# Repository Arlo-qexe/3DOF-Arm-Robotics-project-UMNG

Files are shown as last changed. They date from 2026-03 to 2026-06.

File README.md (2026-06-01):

# Brazo Robótico 3DOF — Proyecto UMNG

Diseño, construcción y control de un brazo robótico de 3 grados de libertad (3-DOF) capaz de ejecutar tareas de manipulación autónoma. El proyecto abarca desde el diseño CAD y simulación hasta la implementación física completa: electrónica, firmware en ESP32, interfaz de control y planificación de trayectorias.

> **Aplicación demo:** clasificación y transporte autónomo de pelotas de ping pong entre posiciones predefinidas.

---

## Robot físico

| Vista lateral | Vista frontal (laboratorio) |
|---|---|
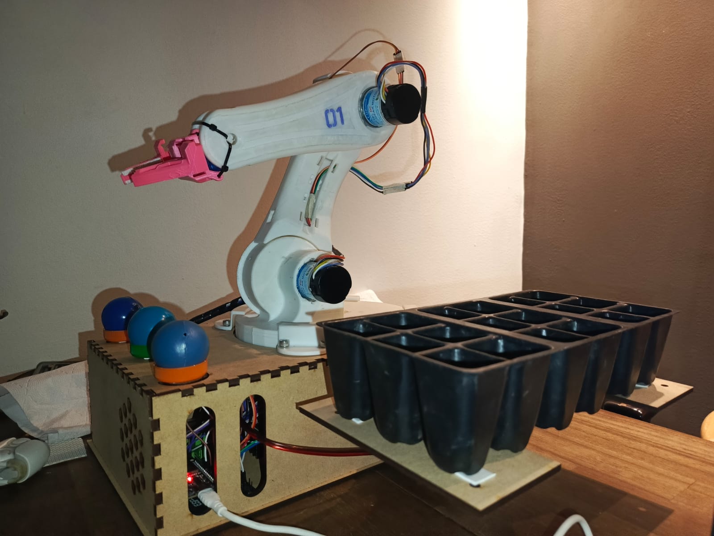
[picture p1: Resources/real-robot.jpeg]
Robot real
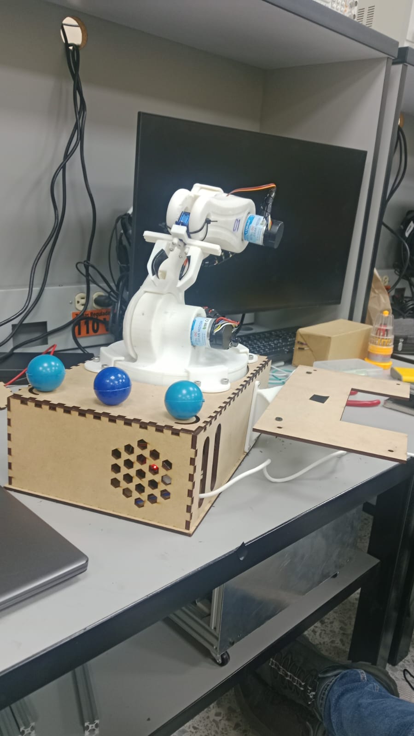
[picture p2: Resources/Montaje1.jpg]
Robot en laboratorio
|  |  |

---

## 🎯 Objetivos

### Objetivo general
Diseñar, construir y controlar un brazo robótico de 3 DOF capaz de posicionar su efector final mediante cinemática directa e inversa, y ejecutar tareas de manipulación autónoma con trayectorias planificadas.

### Objetivos específicos
- Diseñar la estructura mecánica completa (CAD + impresión 3D + corte láser)
- Diseñar e implementar el circuito electrónico de control (PCB personalizada)
- Modelar matemáticamente el sistema (cinemática directa e inversa, Jacobiano)
- Implementar firmware en ESP32 para control de 3 motores DC con encoders
- Desarrollar una interfaz gráfica de control y monitoreo en Python
- Implementar un simulador de planificación de trayectorias
- Integrar simulación en ROS2/Gazebo con modelo URDF
- Ejecutar la tarea de clasificación de pelotas de ping pong

---

## 📂 Estructura del repositorio

```
├── Act/                          → Actas de reuniones del proyecto
├── Documentos/                   → Análisis de contexto y documentación
├── Hardware/
│   ├── CAD/                      → Diseños CAD (SolidWorks, DXF)
│   ├── PCB/                      → PCB personalizada (ESP32 + BTS7960 + 3 motores DC)
│   ├── Gripper/                  → Modelo STL del gripper
│   ├── STLs/ y STLS/             → Piezas impresas en 3D
│   └── Engranaje de Eslabon*.png → Renders de engranajes
├── Resources/
│   ├── VIDEOS/                   → Videos de pruebas y resultado final
│   ├── Trayectorias/             → CSVs de trayectorias (articular y cartesiana)
│   ├── Datos caracterizacion Motores/ → Datos encoder de los 3 motores
│   └── *.png / *.jpg             → Imágenes del proyecto
├── Software/
│   ├── brazo_integrado (4).py    → Interfaz principal de control + planificador
│   ├── abdul3dof_gui.py          → GUI de control de posición
│   ├── Gazebo/                   → Simulación en Gazebo (URDF, workspace ROS2)
│   ├── URDF/                     → Modelo URDF del brazo
│   ├── brazo_robot/              → Paquete ROS2 del robot
│   └── ws_manip/                 → Workspace de manipulación ROS2
├── README.md
└── LICENSE
```

---

## 🔧 Hardware

### Diseño mecánico (SolidWorks)

El brazo fue diseñado completamente en SolidWorks e impreso en 3D. Incluye tres eslabones, base giratoria, gripper y bandeja dispensadora de pelotas.

| Ensamblaje completo | Ensamblaje v1 |
|---|---|
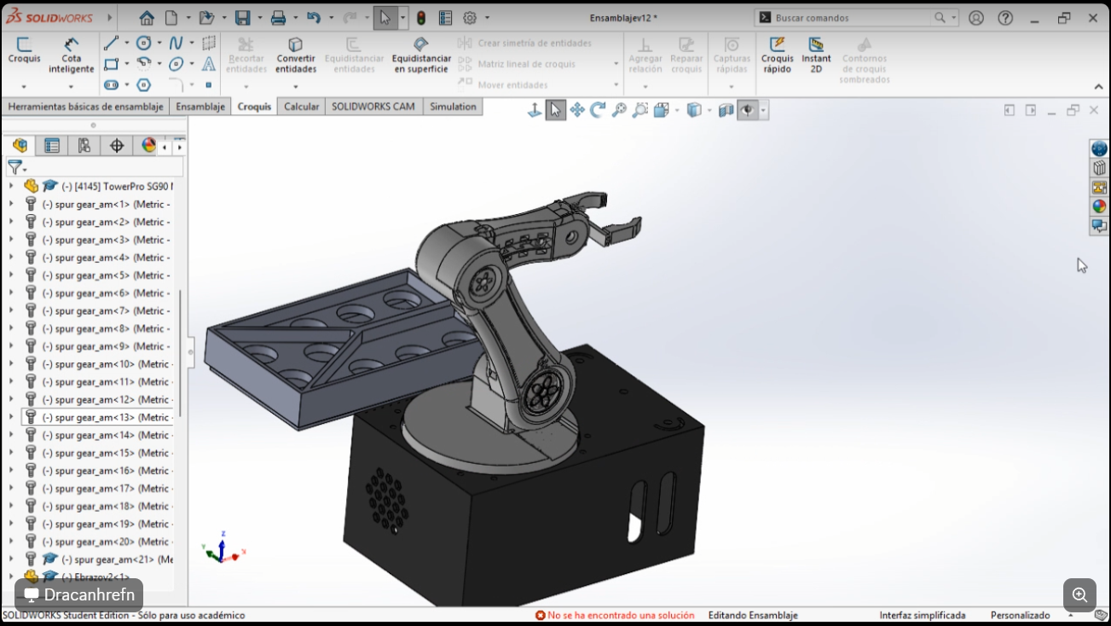
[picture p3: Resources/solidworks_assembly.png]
SolidWorks ensamblaje
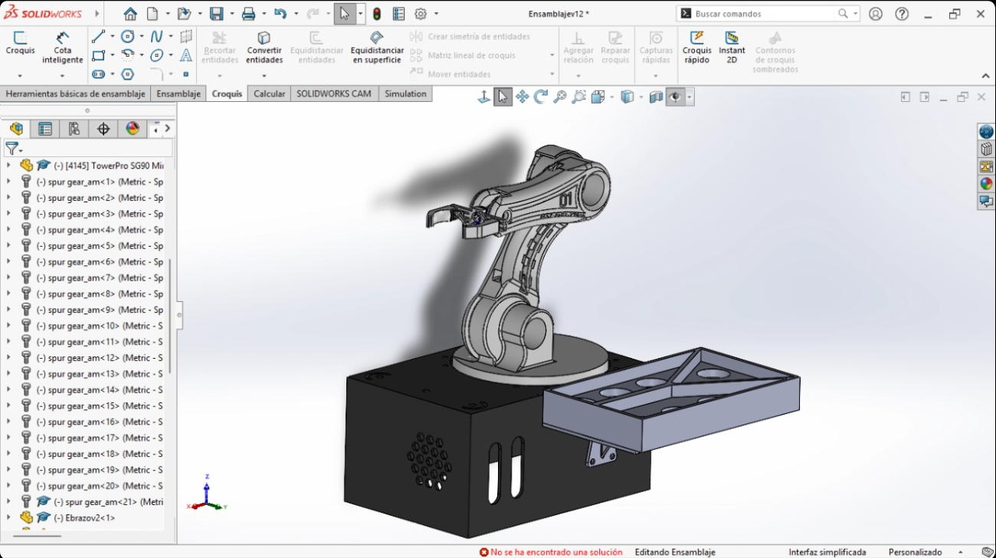
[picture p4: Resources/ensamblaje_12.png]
Ensamblaje anterior
|  |  |

| Dimensiones dispensador | Bandeja ping pong (impresa) |
|---|---|
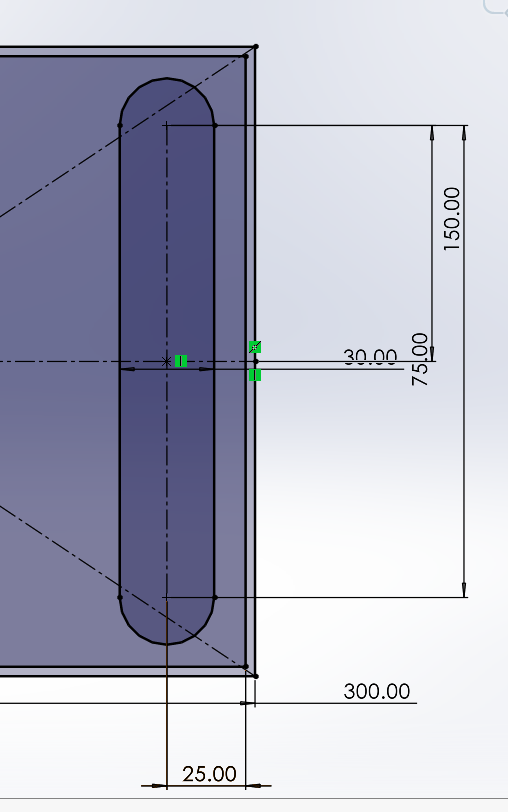
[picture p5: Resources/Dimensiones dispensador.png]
Dimensiones dispensador
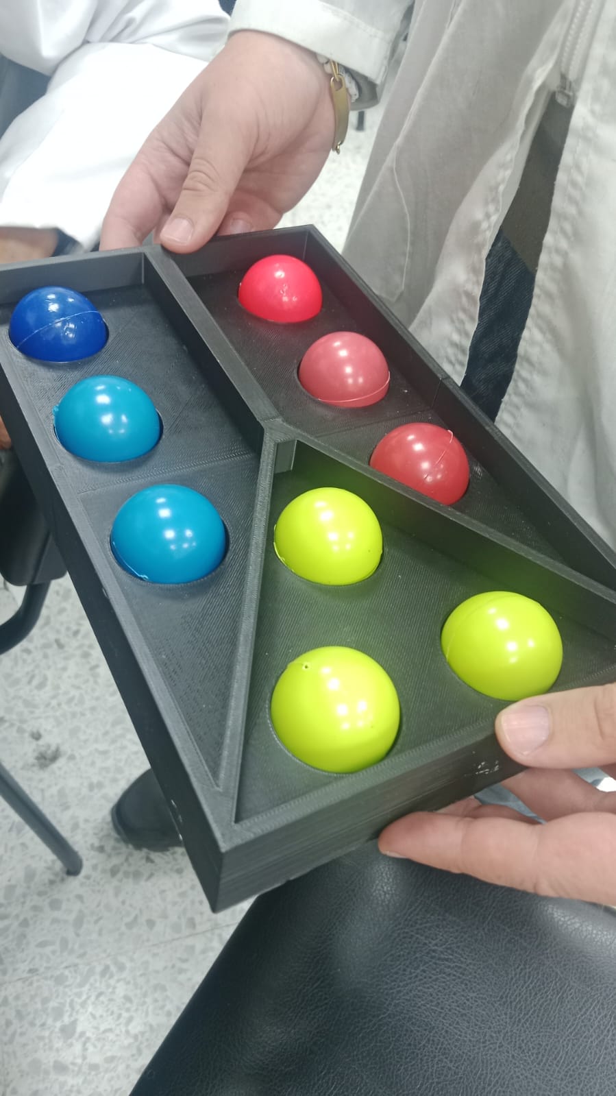
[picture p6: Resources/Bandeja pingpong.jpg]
Bandeja ping pong
|  |  |

### Electrónica — PCB personalizada

Se diseñó e implementó una PCB a medida con:
- **ESP32** como microcontrolador principal
- **BTS7960** (×3) para control de motores DC con PWM
- Conectores de encoder para los 3 motores
- Fabricada en Bogotá (2026-04-10)

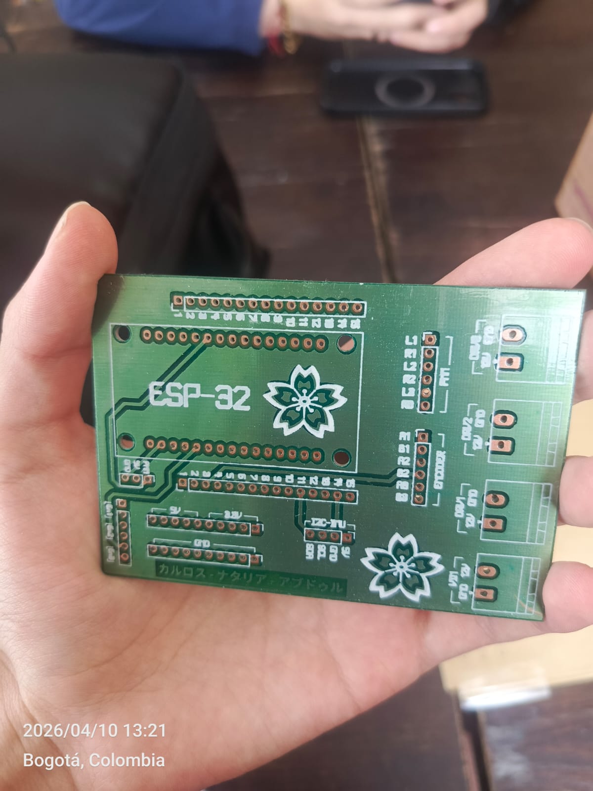
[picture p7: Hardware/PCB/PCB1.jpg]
PCB ESP32 + BTS7960


El esquemático completo está disponible en: [`Resources/Esquemático – ESP32 + BTS7960 + 3 Motores DC.pdf`](Resources/Esquemático%20–%20ESP32%20+%20BTS7960%20+%203%20Motores%20DC.pdf)

---

## 💻 Software

### Interfaz de control de posición

Interfaz gráfica en Python (`abdul3dof_gui.py`) con conexión serial al ESP32:

- Control independiente de 3 motores (M1 Base, M2 Hombro, M3 Codo)
- Visualización 3D en tiempo real de cinemática directa
- Gráfica de posición articular en tiempo real
- Cálculo y ejecución de cinemática inversa
- Reset de posición con un clic

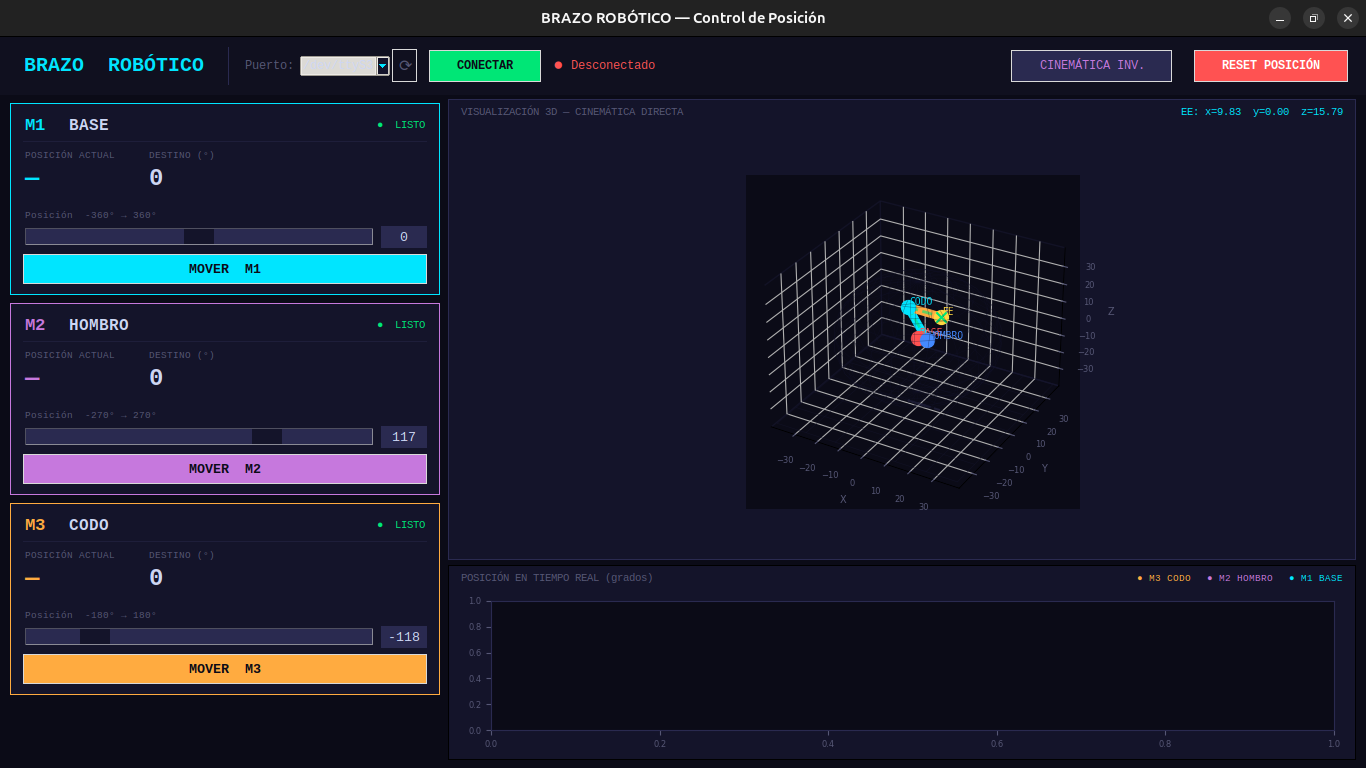
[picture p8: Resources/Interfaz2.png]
Interfaz de control de posición


### Simulador de planificación de trayectorias

El simulador integrado (`brazo_integrado (4).py`) permite planificar y animar trayectorias completas:

- Editor de waypoints (XYZ o articular)
- 3 modos de interpolación: **articular (curva)**, **cartesiana (recta)**, **control cinemático (Jacobiano)**
- Visualización 3D animada de la trayectoria del efector final
- Gráficas: posición articular, velocidad, aceleración y posición XYZ del EE
- Importación de trayectorias desde CSV
- Gripper integrado en la simulación
- Resumen automático: waypoints, tramos, tiempo total

| Planificador de trayectorias (ping pong articular) | Ángulos enviados / control real |
|---|---|
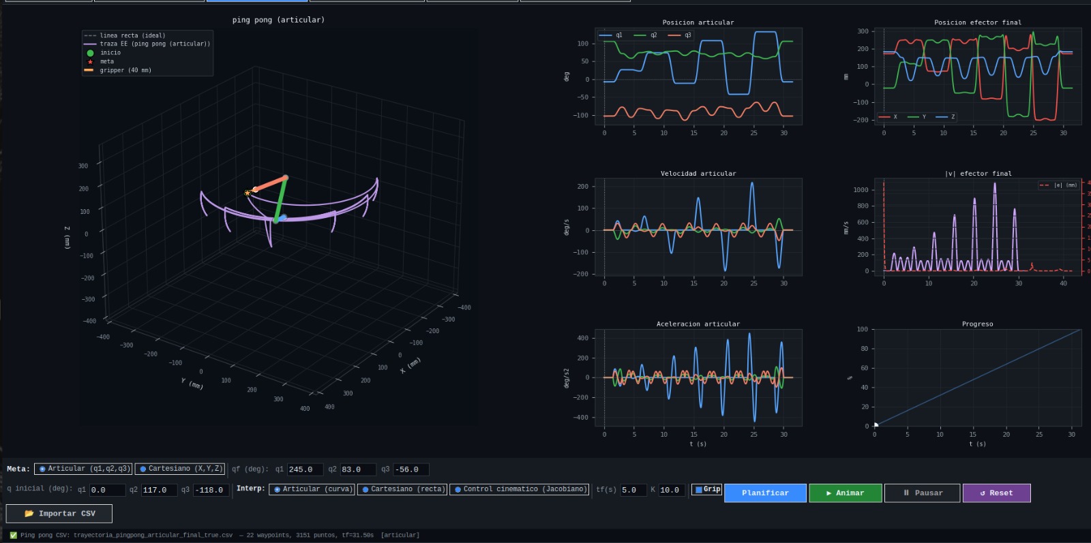
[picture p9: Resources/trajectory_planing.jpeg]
Planificador
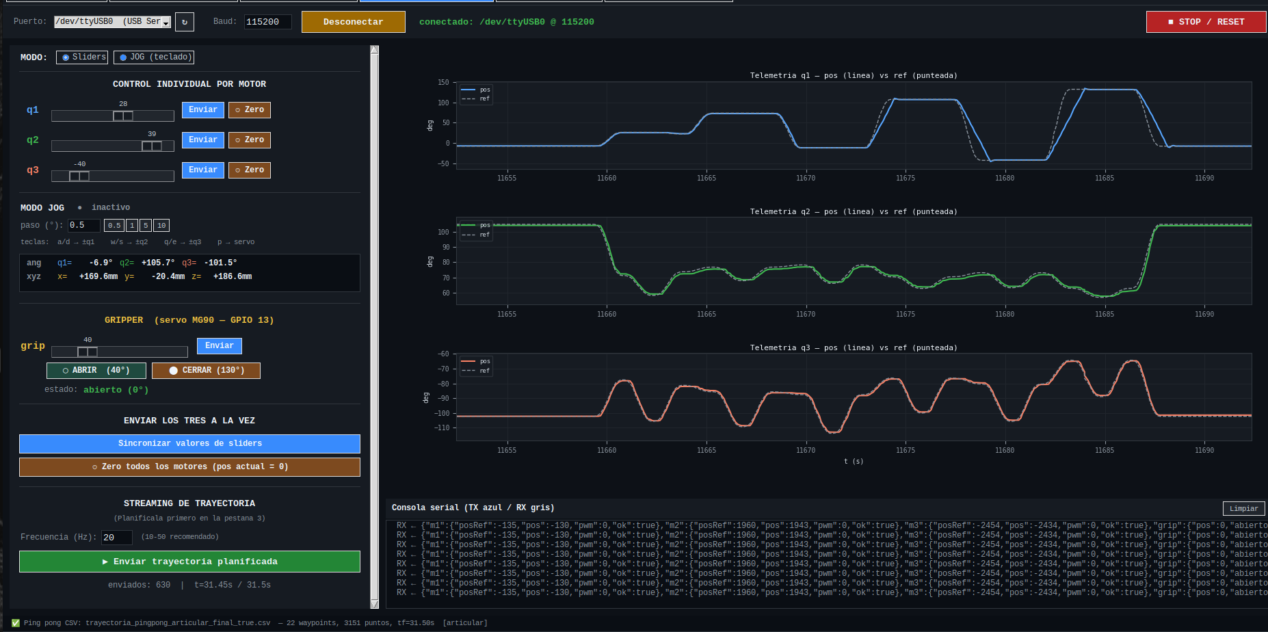
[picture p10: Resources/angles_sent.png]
Ángulos enviados
|  |  |

**Trayectoria ping pong:** 22 waypoints, 21 tramos, tiempo total ≈ 31.5 s, gripper 40 mm de apertura.

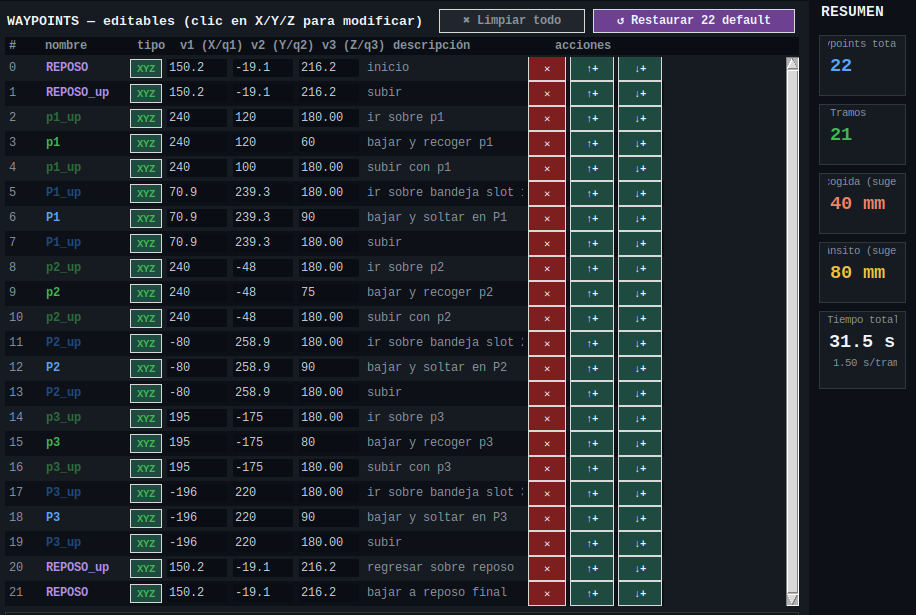
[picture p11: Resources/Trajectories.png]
Waypoints ping pong


### Simulación ROS2 / Gazebo

Simulación completa con modelo URDF en Gazebo y visualización en RViz:

| RViz — modelo 3D | Gazebo + interfaz Python |
|---|---|
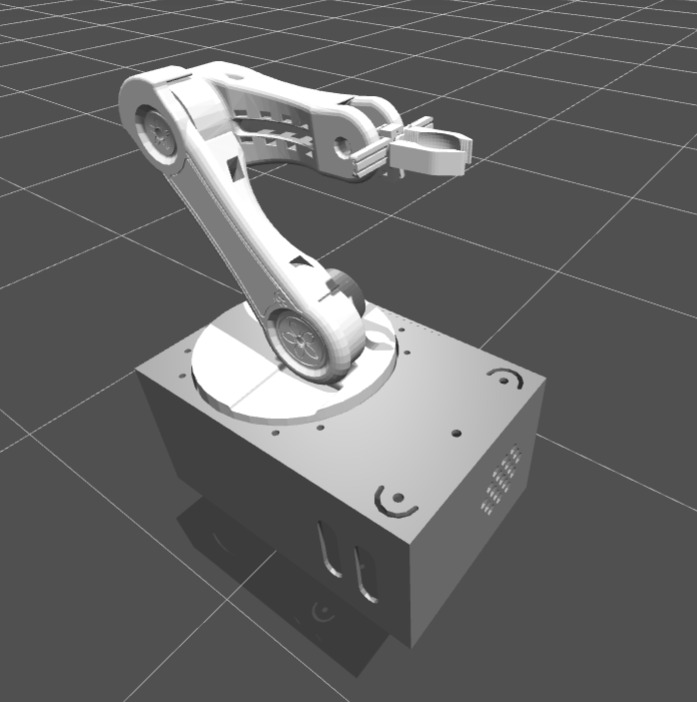
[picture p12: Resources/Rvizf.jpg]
RViz
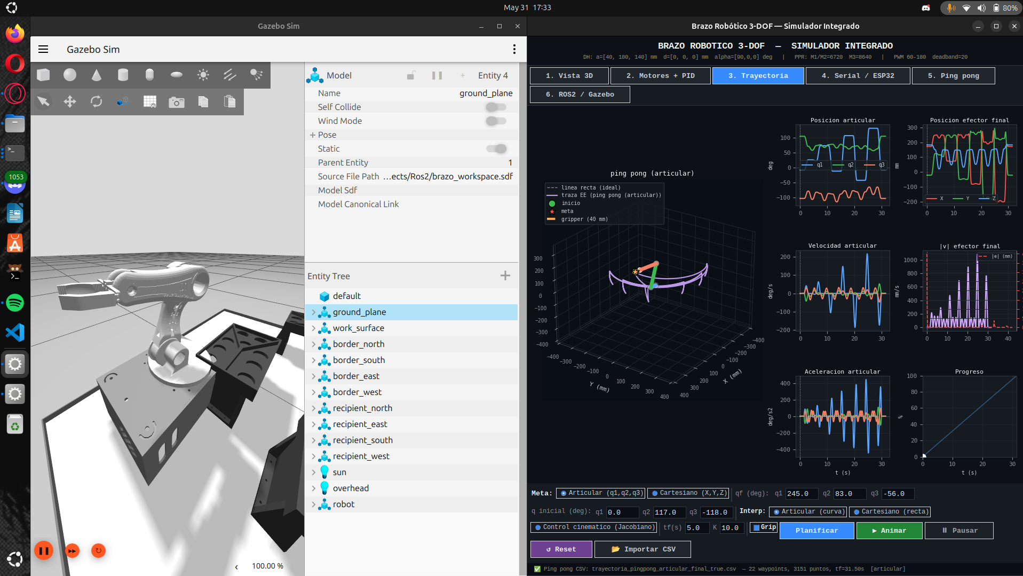
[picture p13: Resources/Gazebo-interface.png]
Gazebo + interfaz
|  |  |

### Cinemática inversa interactiva

Archivo HTML autocontenido (`Resources/cinematica_inversa_interactiva.html`) para explorar visualmente la cinemática inversa del brazo en el navegador, sin instalación adicional.

---

## 🏓 Aplicación: clasificación de pelotas de ping pong

El robot ejecuta una secuencia autónoma de pick & place: recoge pelotas del dispensador y las deposita en posiciones predefinidas de una bandeja receptora.

- **Dispensador:** bandeja 3D-impresa con ranuras para pelotas de colores
- **Gripper:** pinza impresa en 3D (apertura 40 mm)
- **Trayectoria:** planificada con el simulador y cargada via CSV al firmware
- **Ejecución:** ~31.5 s por ciclo completo (3 pelotas)

**Video — prueba final:**
<video src="https://raw.githubusercontent.com/Arlo-qexe/3DOF-Arm-Robotics-project-UMNG/main/Resources/VIDEOS/video_final.mp4" controls width="720"></video>
Más videos de prueba en [`Resources/VIDEOS/`](Resources/VIDEOS/)

---

## 📊 Caracterización de motores

Se midieron y registraron curvas de velocidad y posición (encoder) para los 3 motores bajo distintas condiciones:

```
Resources/Datos caracterizacion Motores/
├── M1_Encoder_data_210.csv
├── M2_Encoder_data_rads_210.csv
├── M3_Encoder_data_rads_270.csv
└── ...
```

---

## 👩‍💻 Autores

Proyecto desarrollado por estudiantes de Ingeniería — **Universidad Militar Nueva Granada (UMNG)**:

- **Carlos Andrés Quintero Forero**
- **Salim Abdul Fayad Diaz**
- **Natalia Almanza**

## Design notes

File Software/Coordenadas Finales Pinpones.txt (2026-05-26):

Coordenadas Finales Pinpones:
	z = -50m (+20mm con altura pingpong + 80mm movimiento previo)
	y = +162.99mm
	x1= -34.87mm
	x2= +25.13mm
	x3= +85.13mm
Coordenadas Recogida Pinpones:

	z = -50mm (+20mm con altura pingpong)
	x = 172mm
	y = 75mm

Coordenadas Descanso:

	z = 197.01mm
	x = 125.23mm
	y = 19.87mm

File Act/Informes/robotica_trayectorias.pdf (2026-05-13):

# Planificación Trapezoidal de Trayectorias Articulares

### Natalia Almanza, Abdul Fayad, Carlos Quintero

### 27 de marzo de 2026

## 1. Fundamento Teórico

### 1.1. Perfil Trapezoidal

El perfil trapezoidal de velocidad consta de tres fases:

Aceleración constante

Velocidad constante

Desaceleración constante

El tiempo de aceleración se define como:

ta =

Vmax
a

(1)

La distancia recorrida durante la aceleración es:

da =

1
2

at²
a

(2)

Dependiendo del desplazamiento total D, el perfil puede ser:

Triangular: no se alcanza la velocidad máxima.

Trapezoidal: existe fase de velocidad constante.

### 1.2. Sincronización Temporal

Cada articulación posee un tiempo natural distinto. Para sincronizar el movimiento se utiliza un factor de escala temporal:

ratio =

ttotal
tf

(3)

Recalculando:

t

′
a = ratio · ta | (4)
t

′
c = ratio · tc | (5)

La nueva velocidad pico queda:

Vp =

|D|
t

′
a + t

′
c

(6)

y la aceleración:

aj =

Vp
t

′
a

(7)

## 2. Metodología

El algoritmo desarrollado sigue los siguientes pasos:

1. Definición del tiempo total de movimiento.
2. Establecimiento de posiciones iniciales y finales.
3. Cálculo del perfil natural de cada junta.
4. Escalamiento temporal.
5. Generación de posición, velocidad y aceleración.
6. Visualización gráfica.

## 3. Código Implementado

clc; clear ; close all;

t_total = 5;
dt = 0.001;
t = 0: dt : t_total ;
n = length ( t ) ;

q0 = [0 117 -118];
qf = [245 83 -56];

Vmax = [20 15 10];
a = [10 10 10];

q = zeros (3 , n ) ;
qd = zeros (3 , n ) ;
qdd = zeros (3 , n ) ;

tf_vec = zeros (1 ,3) ;
Vp_vec = zeros (1 ,3) ;
ta_vec = zeros (1 ,3) ;
tc_vec = zeros (1 ,3) ;

for j = 1:3

25 D = qf ( j ) - q0 ( j ) ;

26
27 | ta = Vmax ( j ) / a ( j ) ;
28 | da = 0.5* a ( j ) * ta ^2;

29
30 | if (2* da > abs( D ) )
31 | ta = sqrt (abs( D ) / a ( j ) ) ;
32 | tc = 0;
33 | tf = 2* ta ;
34 | Vp = a ( j ) * ta ;
35 | else
36 | tc = (abs( D ) -2* da ) / Vmax ( j ) ;
37 | tf = 2* ta + tc ;
38 | Vp = Vmax ( j ) ;
39 | end

40
41 | tf_vec ( j ) = tf ;
42 | Vp_vec ( j ) = Vp ;
43 | ta_vec ( j ) = ta ;
44 | tc_vec ( j ) = tc ;
45 | end

## 4. Resultados

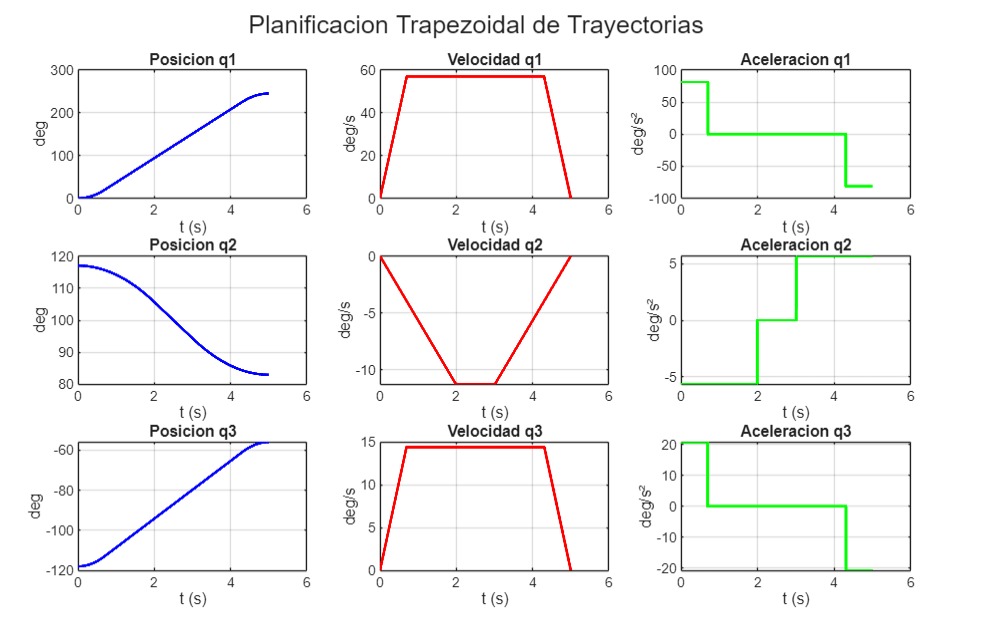
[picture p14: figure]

Figura 1: Gráficas resultados velocidad trapezoidal

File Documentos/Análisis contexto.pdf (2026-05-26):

INFORME DE PRÁCTICA DE LABORATORIO | Versión 1.0
PROGRAMA DE INGENIERÍA MECATRÓNICA
Periodo 2024-2

## Análisis de Contexto: Sistema Robótico de Ensamble Pick-and-Place de 3 GDL para Líneas de Empaque Industrial

Carlos Andrés Quintero Forero, Natalia Almanza Velasco, Abdul Ingeniería en Mecatrónica — Universidad Militar Nueva Granada

Profesora: Alexandra Elizabeth Velasco

Resumen—Este documento presenta el análisis de contexto de dos sistemas robóticos manipuladores antropomórficos de 3 grados de libertad (GDL) diseñados para tareas de pick-and-place en líneas de empaque industrial. El primer sistema atiende el empaque de chocolates individuales en una
caja, | bajo | restricciones | de | higiene
alimentaria. El segundo sistema aborda el empaque de lápices de colores en caja, con énfasis en la protección del acabado superficial del producto. Para cada caso se establecen los requisitos funcionales y no funcionales, restricciones y limitaciones del sistema, selección de materiales y la relación entre el contexto de aplicación y los criterios de diseño.
Palabras | clave: | robot | manipulador;
pick-and-place; 3 GDL; empaque industrial; selección de materiales; cinemática.
I. | ANÁLISIS | DE | CONTEXTO | 1:
ENSAMBLADORA | DE | CAJA | DE
CHOCOLATES
A. Descripción
Se | diseña | un | robot | manipulador
antropomórfico de 3 GDL para tomar
chocolates | individuales | previamente
organizados en bandejas de alimentación con posiciones conocidas y ubicarlos en una caja de empaque siguiendo una distribución específica (orden y orientación definidos según el producto). El sistema realiza tareas repetitivas de pick-and-place en un entorno de producción alimentaria

controlado.
Los chocolates presentan geometría, masa y dimensiones similares entre sí, por lo que no se requiere identificación visual. El robot se desplaza hasta posiciones predefinidas, toma cada unidad mediante un efector final diseñado para el agarre de elementos de baja masa y geometría regular, transporta cada pieza y la posiciona en la celda correspondiente dentro de la caja de empaque, en el orden establecido por el proceso productivo.

B.Justificación Técnica del Alcance
Los chocolates poseen tamaños, pesos y espesores similares y sus posiciones de origen son conocidas y fijas. Por ello, el diseño del sistema se centra en la cinemática del manipulador (incluyendo el efector final) y la planeación de trayectorias con precisión de posicionamiento (control).

C.Requisitos Funcionales

- Tomar unidades de chocolate desde posiciones predefinidas en la bandeja de alimentación, respetando el orden de llenado de la caja.
- Transportar cada pieza desde la estación de origen hasta la caja de empaque.
- Posicionar cada chocolate en la celda correcta con orientación y orden definidos.
- Ejecutar movimientos repetitivos con precisión y repetibilidad durante ciclos continuos de producción.

El presente documento corresponde a un informe de práctica de laboratorio de “Electrónica de potencia” presentado en la Universidad Militar Nueva Granada durante el periodo 2026-1.

- | Operar | mediante | secuencias
automáticas | programadas | sin
intervención del operario durante el
ciclo.
D. Requisitos No Funcionales
- El robot debe operar de manera segura en presencia de operarios en la línea de producción, evitando colisiones y movimientos bruscos.
- El | manipulador | debe | garantizar
movimientos suaves y estables para no deformar ni dañar las piezas de chocolate durante el agarre y el transporte.El error de posicionamiento debe mantenerse cercano a cero para garantizar el llenado correcto de la caja.
- El tiempo de ciclo debe ser compatible con la cadencia de producción de la línea.
- Los materiales del efector final deben ser aptos para contacto con alimentos, cumpliendo la norma FDA 21 CFR y estándares equivalentes [1].
- El robot debe operar dentro del espacio disponible en la estación de empaque.
- Capacidad de carga: El sistema maneja unidades de baja masa (chocolates individuales de entre 5 g y 20 g aproximadamente), por lo que no se requiere alta capacidad de carga.
- Seguridad: El manipulador debe contar con límites de operación que reduzcan riesgos para los operarios en línea.
- Higiene: Los materiales del efector final y de la estructura expuesta deben cumplir normas de contacto con alimentos y permitir limpieza y desinfección frecuente [2].
F. Limitaciones del Sistema
- El manipulador tiene 3 grados de libertad.
- El sistema no incorpora visión artificial. Los chocolates deben estar ubicados en posiciones predefinidas y fijas.
- El robot solo puede manipular unidades de tamaño, forma y peso

similares.
- La capacidad de carga es reducida (limitación académica y funcional).
- El espacio de trabajo del robot está restringido al alcance geométrico del manipulador y al espacio disponible en la estación.
- La velocidad de las junturas es de 2 rad/s (máximo).
- El sistema no toma decisiones
autónomas | sobre | el | proceso
productivo ni controla la calidad del producto.
G. Materiales del Efector Final y la Estructura
1) Acero Inoxidable AISI 316L
Este es el material de referencia para componentes estructurales y el efector final en contacto o proximidad con alimentos. Presenta alta resistencia a la corrosión ante agentes de limpieza (ácidos, álcalis, hipoclorito de sodio) y cumple los estándares de la norma 3-A Sanitary Standards y la regulación FDA 21 CFR Part 178 [1][3]. El acero AISI 316L es preferido sobre el 304 por su mayor contenido de molibdeno (2–3 %), que mejora la resistencia a la corrosión por cloruros presentes en los agentes de
limpieza | CIP | (Clean-In-Place)
empleados en la industria de confitería [3].
2) Poliuretano Alimenticio (Food-Grade PU)
Las superficies del efector que contactan directamente el chocolate deben ser de un elastómero flexible, inerte y apto para contacto con alimentos. El poliuretano food-grade cumple la norma FDA 21 CFR 177.2600 [1] y proporciona la fricción necesaria para el agarre sin marcar ni deformar la superficie del chocolate. Su dureza (Shore A 40–60) amortigua el impacto del contacto inicial, protegiendo la integridad del producto [4].

3) Polipropileno | (PP) | Grado
Alimentario
Componentes no estructurales como guías, soportes de cableado y carcasas de protección pueden fabricarse en PP grado alimentario (cumple FDA 21 CFR 177.1520) [1], material de bajo costo, resistente a la humedad y a los detergentes alcalinos empleados en la limpieza de equipos en líneas de confitería [4].

II. PROCEDIMIENTO

Parte I. Generación de Señal SPWM

Inicialmente se planteó una frecuencia portadora de:

fc = 1kHz

Sin embargo, durante el desarrollo de la práctica se decidió aumentar la frecuencia portadora a:

fc = 7kHz

Esto se realizó con el objetivo de mejorar el índice de modulación en frecuencia y obtener una señal SPWM con menor distorsión armónica y una aproximación más adecuada a una onda sinusoidal.

Período de la señal moduladora

Tm = | =
| 1 f

1
60 = 16. 67 ms

Período de la señal portadora

Tc = =

1
f

1
| 7000 = 142. 86 µs

Índice de modulación en frecuencia

mf =

fc
fm

Donde:

- fc: frecuencia portadora
- fm: frecuencia moduladora

Con:

- fc= 7 kHz
- fm = 60 Hz

Se obtiene:

mf =

7000
60 = 116. 67

Esto significa que existen aproximadamente:

- 117 pulsos PWM por cada ciclo senoidal.

Índice de modulación en amplitud

Se define como:

ma =

Vm
Vc

Suponiendo:

- Amplitud sinusoidal:

Vm = 5v

- Amplitud triangular:

Vc = 5v

Entonces:

ma =

5
5 = 1

El sistema trabaja en zona lineal de modulación.

Voltaje RMS de la salida

Vo(rms) =

ma·Vdc
2 2

Sustituyendo:

Vo(rms) = | = 8.49 V (1)·(24) 2 2

Corriente RMS en la carga

Irms = = 0.849 V

8.49
10
Potencia entregada a la carga

P = Vrms · Irms

Sustituyendo

P = (8. 49) · (0. 89) = 7. 21 W

Frecuencia angular de la señal sinusoidal

Para 60 Hz:

w = 2π(60) = 376. 99 rad/s

IV. ANÁLISIS DE RESULTADOS

Durante el desarrollo de la práctica se
implementó | un | programa | en | el
microcontrolador que permitió modificar dinámicamente la frecuencia de salida del
inversor | monofásico. | El | sistema | fue
configurado para variar la frecuencia en intervalos de 30 Hz, realizando pruebas desde 180 Hz hasta 30 Hz.
1. Señal de aproximadamente 180 Hz

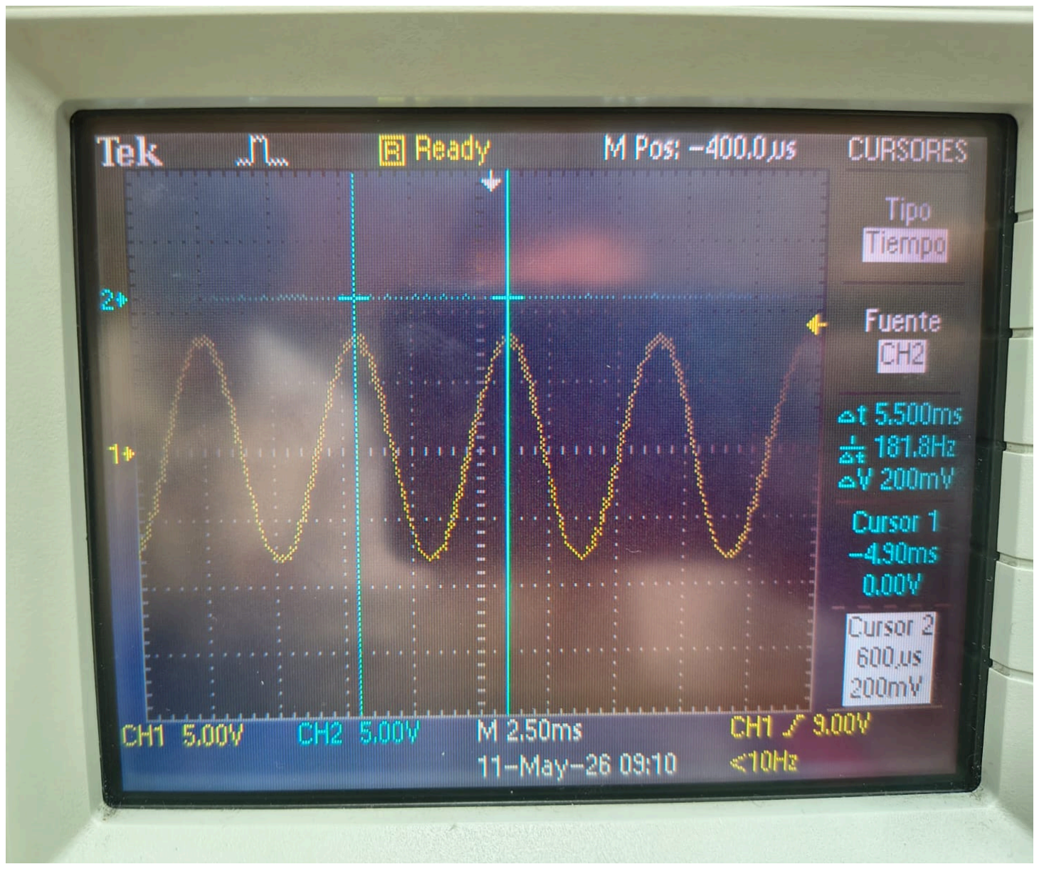
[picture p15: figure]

En la primera medición se obtuvo una diferencia temporal de:

Δt = 5. 50 ms

Por tanto, la frecuencia calculada fue:

f =

1
5.50 · 10

−3 = 181. 8 Hz

El valor medido presenta una pequeña variación respecto al valor programado, asociada principalmente a la resolución temporal del osciloscopio y al ajuste manual de los cursores.

2. Señal de aproximadamente 150 Hz

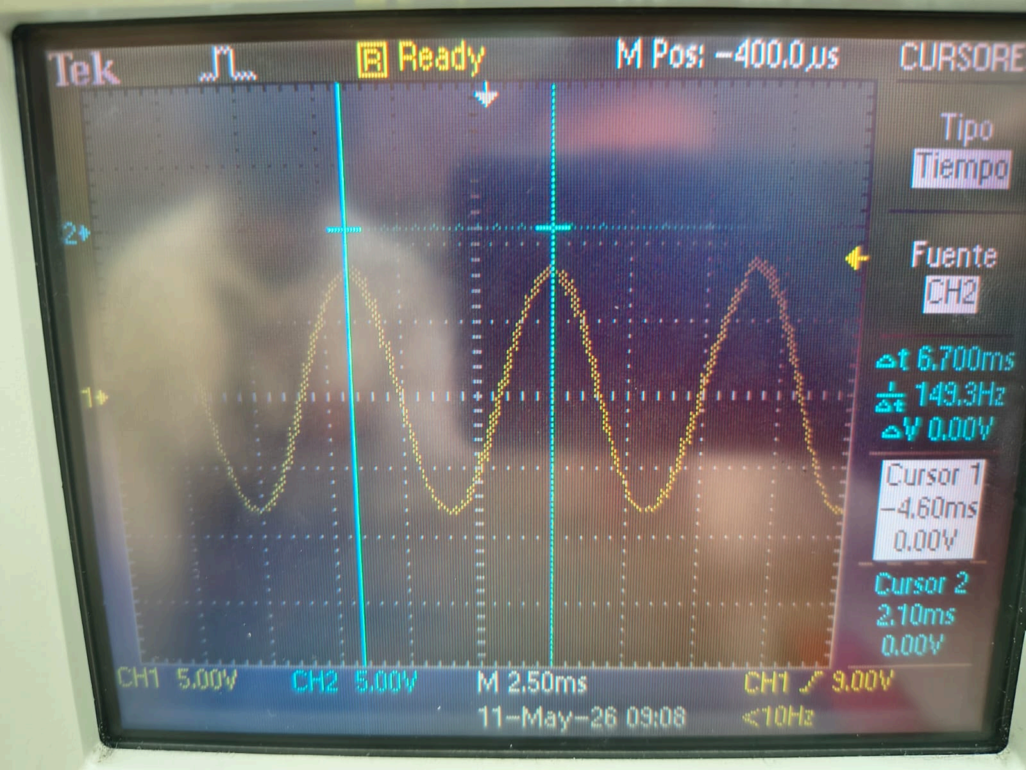
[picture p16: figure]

En la segunda medición se registró:

Δt = 6. 70 ms

Por tanto, la frecuencia calculada fue:

f =

1
6.70 · 10

−3 = 149. 3 Hz

La señal conservó una forma senoidal estable y simétrica.

3. Señal de aproximadamente 120 Hz

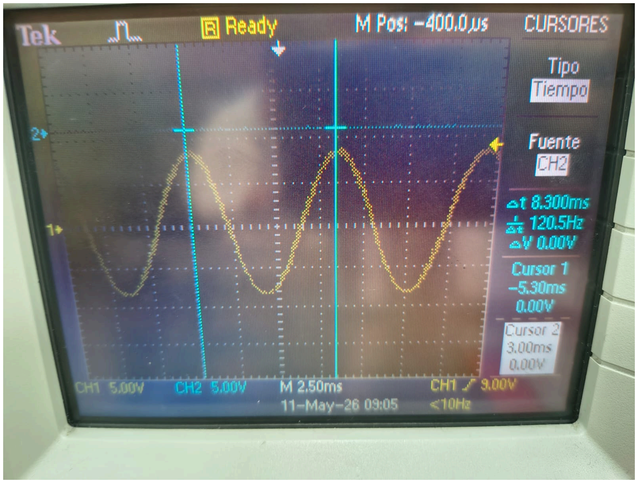
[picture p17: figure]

En la tercera medición se obtuvo una diferencia temporal de:

Δt = 8. 30 ms

Por tanto, la frecuencia calculada fue:

f =

1
8.30 · 10

−3 = 120. 5 Hz

El resultado obtenido coincide adecuadamente con el valor esperado.

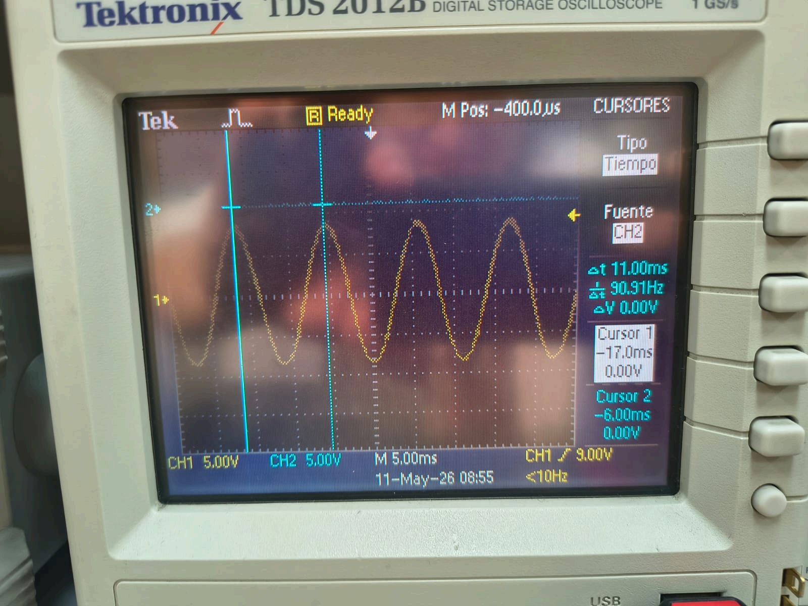
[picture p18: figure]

4. Señal de aproximadamente 90 Hz

En la cuarta medición se obtuvo:

Δt = 11. 00 ms

Por tanto, la frecuencia calculada fue:

f =

1
11.00 · 10

−3 = 90. 91Hz

5. Señal de aproximadamente 60 Hz

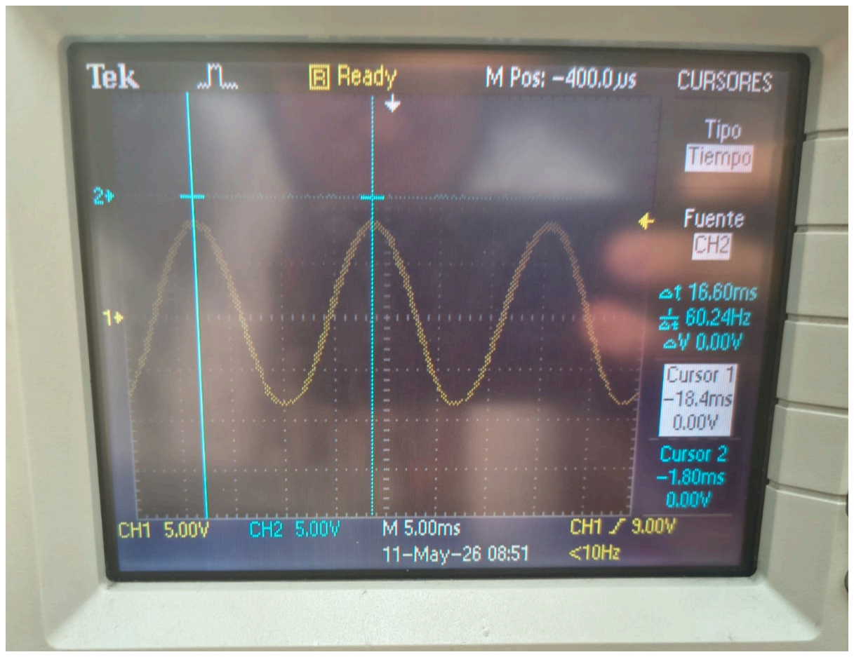
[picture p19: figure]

En la quinta medición se obtuvo:

Δt = 16. 60 ms

Por tanto, la frecuencia calculada fue:

f =

1
16.60 · 10

−3 = 60. 24 Hz

La medida presentó un error muy pequeño

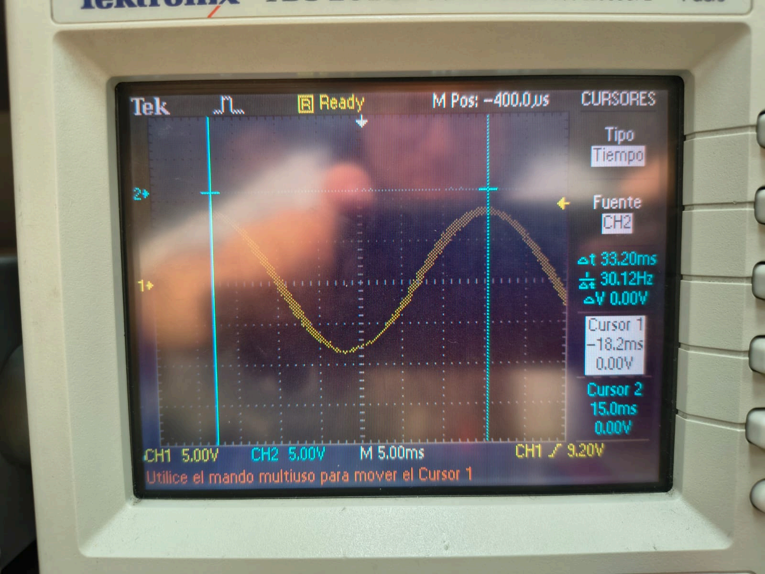
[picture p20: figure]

respecto | al | valor | programado,
aproximadamente 0.4%.
6. Señal aproximadamente de 30Hz

En la quinta medición se obtuvo:

Δt = 33. 20 ms

Por tanto, la frecuencia calculada fue:

f =

1
33.20 · 10

−3 = 30. 12Hz

La señal presentó un incremento evidente en el período, manteniendo una forma senoidal estable.

Tabla comparativa de resultados obtenidos

Frecuencia Programada Hz | Frecuencia medida | Error %
180 | 181.8 | 1.0
150 | 149.3 | 0.47
120 | 120.5 | 0.42
90 | 90.91 | 1.01
60 | 60.24 | 0.4
30 | 30.12 | 0.4

Se observó que:

- La frecuencia medida coincide satisfactoriamente con los valores programados.
- Los errores obtenidos fueron
pequeños | y | aceptables
experimentalmente.
- La señal mantuvo una forma aproximadamente sinusoidal en todos los casos.
- La | técnica | SPWM | permitió
conservar estabilidad incluso a frecuencias bajas.
- El incremento de la frecuencia portadora a 7 kHz ayudó a mejorar la calidad de la señal y disminuir el contenido armónico visible.

En general, el sistema presentó un comportamiento estable y adecuado para
aplicaciones | de | conversión DC–AC
monofásica.
V. CONCLUSIONES

Se logró implementar satisfactoriamente un convertidor DC–AC monofásico utilizando modulación SPWM, permitiendo generar señales con comportamiento aproximado a una onda sinusoidal.

El microcontrolador permitió variar la frecuencia de salida de manera programable, realizando pruebas desde 180 Hz hasta 30 Hz en intervalos de 30 Hz, verificando la flexibilidad y precisión del sistema de control.

Las mediciones realizadas con el osciloscopio demostraron que las frecuencias obtenidas experimentalmente fueron muy cercanas a los valores programados, presentando errores mínimos menores al 1 %.

El aumento de la frecuencia portadora de 1 kHz a 7 kHz mejoró significativamente el índice de modulación en frecuencia, permitiendo obtener una señal SPWM de mejor calidad y con menor distorsión armónica.

Se comprobó que al incrementar la frecuencia portadora los armónicos se desplazan hacia frecuencias más altas, facilitando el filtrado y mejorando la forma de onda de salida.

Experimentalmente se observó que la señal mantuvo estabilidad y simetría en todos los valores de frecuencia evaluados, demostrando el correcto funcionamiento tanto de la etapa de control como de la etapa de potencia.

La | práctica | permitió | comprender | el
funcionamiento de los inversores monofásicos, la importancia de la modulación SPWM y la relación entre la frecuencia portadora y la calidad de la señal de salida en sistemas de electrónica de potencia.

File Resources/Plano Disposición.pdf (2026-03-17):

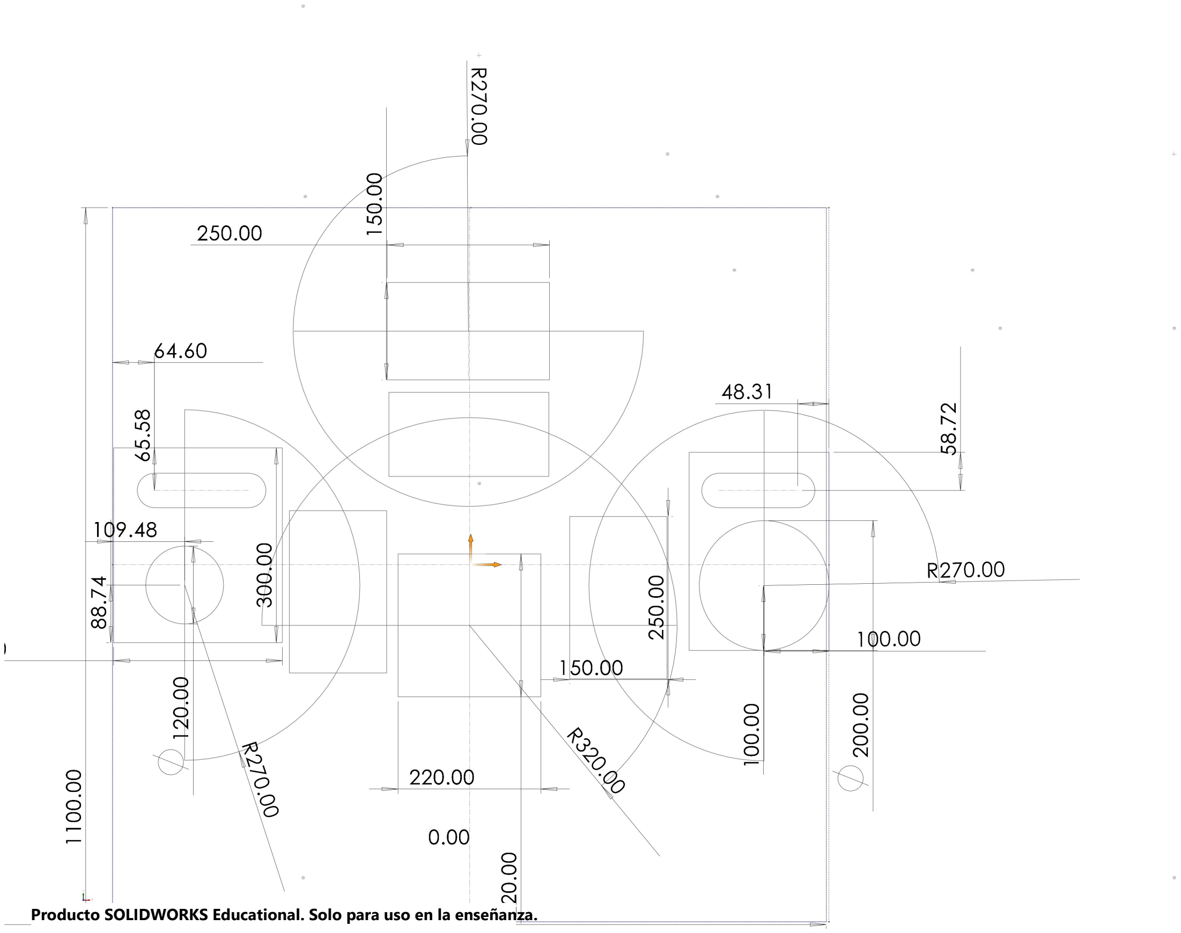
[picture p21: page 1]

Producto SOLIDWORKS Educational. Solo para uso en la enseñanza.

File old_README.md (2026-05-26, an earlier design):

# 3DOF-Arm-Robotics-project-UMNG
Este proyecto consiste en el diseño, modelado y simulación de un brazo robótico de 3 grados de libertad (3DOF). 
Incluye el desarrollo mecánico (CAD), simulación en software, código de control y una interfaz interactiva 
para visualizar la cinemática inversa.

# 🎯 Objetivos

# Objetivo general
Diseñar y simular un brazo robótico de 3 grados de libertad capaz de posicionar su efector final mediante 
cinemática directa e inversa.

# Objetivos específicos
- Diseñar la estructura mecánica del brazo (CAD)
- Modelar matemáticamente el sistema
- Implementar la cinemática directa
- Implementar la cinemática inversa
- Crear una simulación interactiva
- Documentar el proceso de desarrollo

# 📂 Estructura del repositorio
├── Act/                     → Actas de trabajo del proyecto
├── Hardware/                → Diseños CAD del brazo robótico
├── Resources/               → Archivos auxiliares (HTML, documentación, etc.)
├── Software/Simulaciones/   → Código de simulación e interfaz en Python
├── README.md
└── LICENSE

# 🤖 Descripción del sistema

El sistema está compuesto por un brazo robótico de 3 grados de libertad:

- Articulación 1: Rotación de la base
- Articulación 2: Movimiento del primer eslabón
- Articulación 3: Movimiento del segundo eslabón
- Efector final: Posicionamiento en el plano

Ensamblaje en SolidWorks

El modelo permite calcular:
- Cinemática directa
- Cinemática inversa
- Posición del efector final

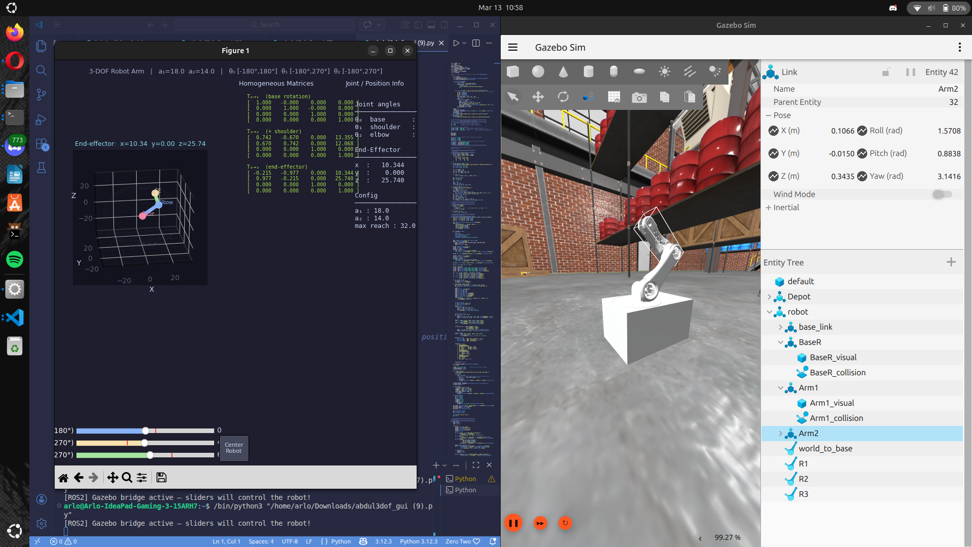
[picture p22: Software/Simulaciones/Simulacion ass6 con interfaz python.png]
Simulacion Gazebo en conexión con interfaz propia en python


Conexión de interfaz con el control de posicion de motores
- Conexión Serial con ESP32
- Comparación de posicion estimada y actual
- Visualizacion de pose
- Cinematica inversa y directa
- Movimiento independiente de 3 Motores

Interfaz conexión con motres

# 👩‍💻 Autores

Proyecto desarrollado por:

- Carlos Andrés Quintero Forero
- Salim Abdul Fayad Diaz
- Natalia Almanza
- Estudiantes de Ingeniería (UMNG)

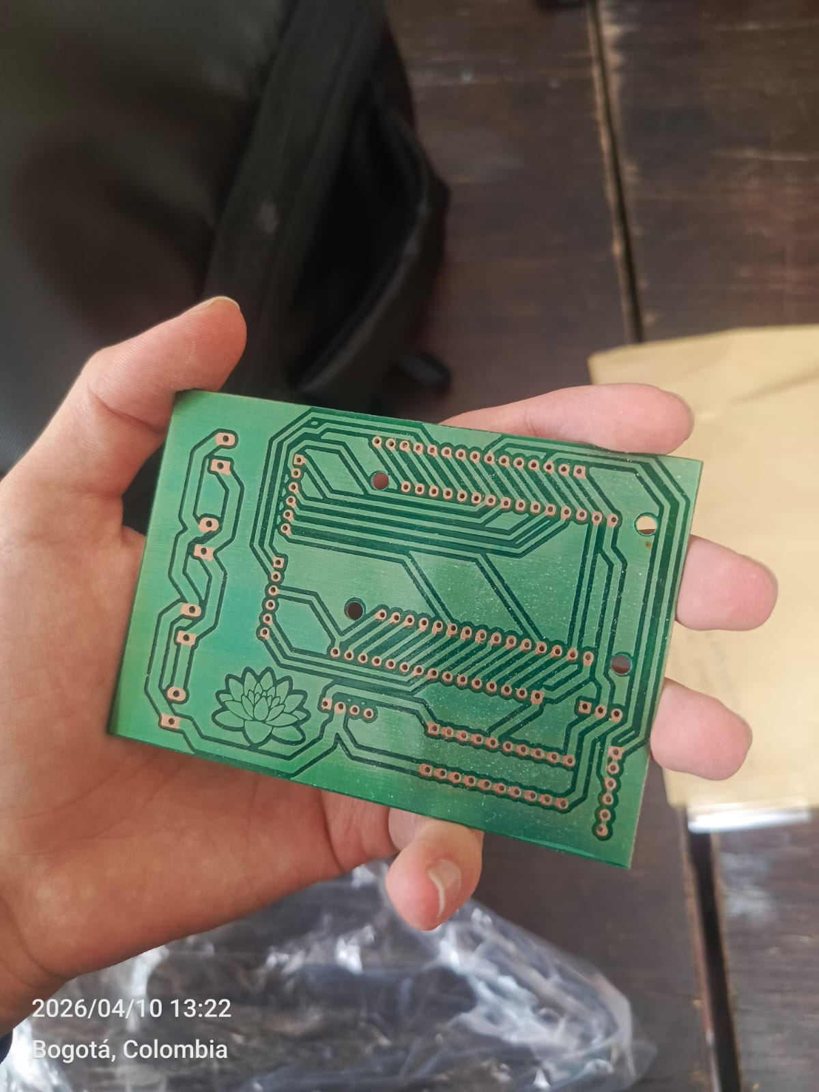
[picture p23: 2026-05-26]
Hardware/PCB/PCB2.jpg

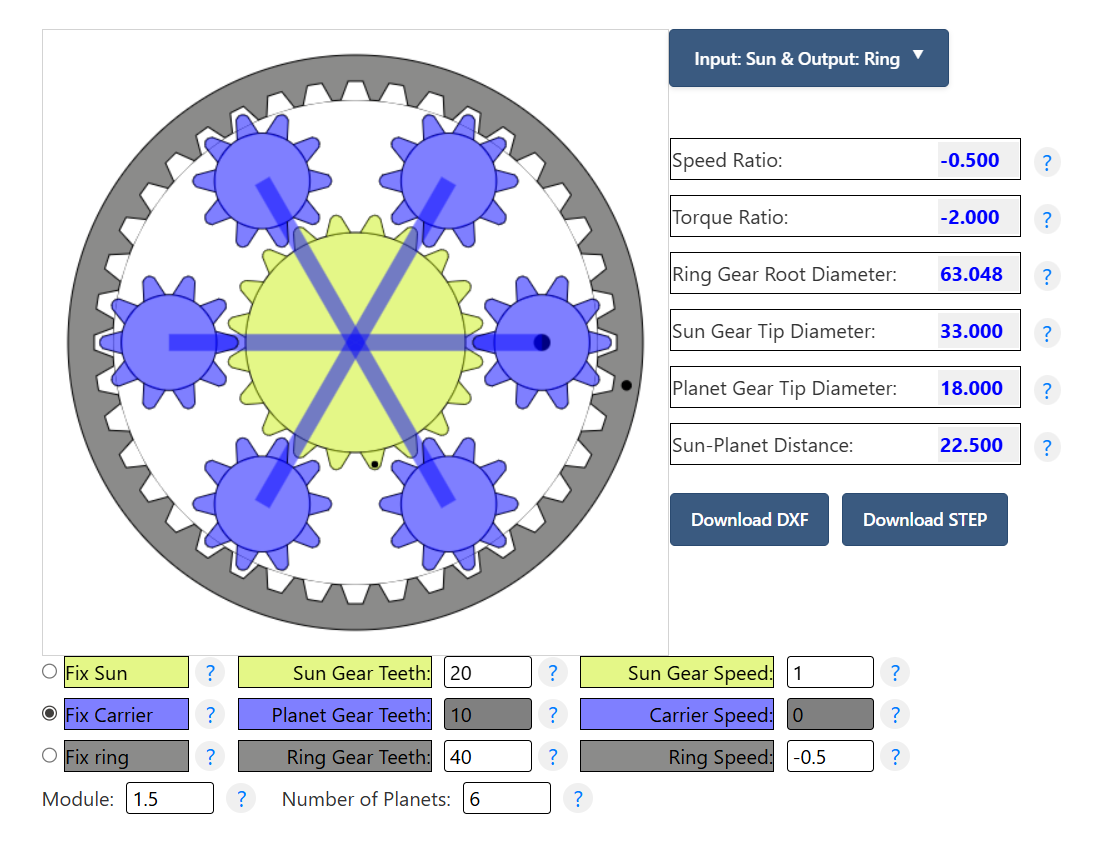
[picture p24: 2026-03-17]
Hardware/Engranaje de Eslabon Brazo 1.png

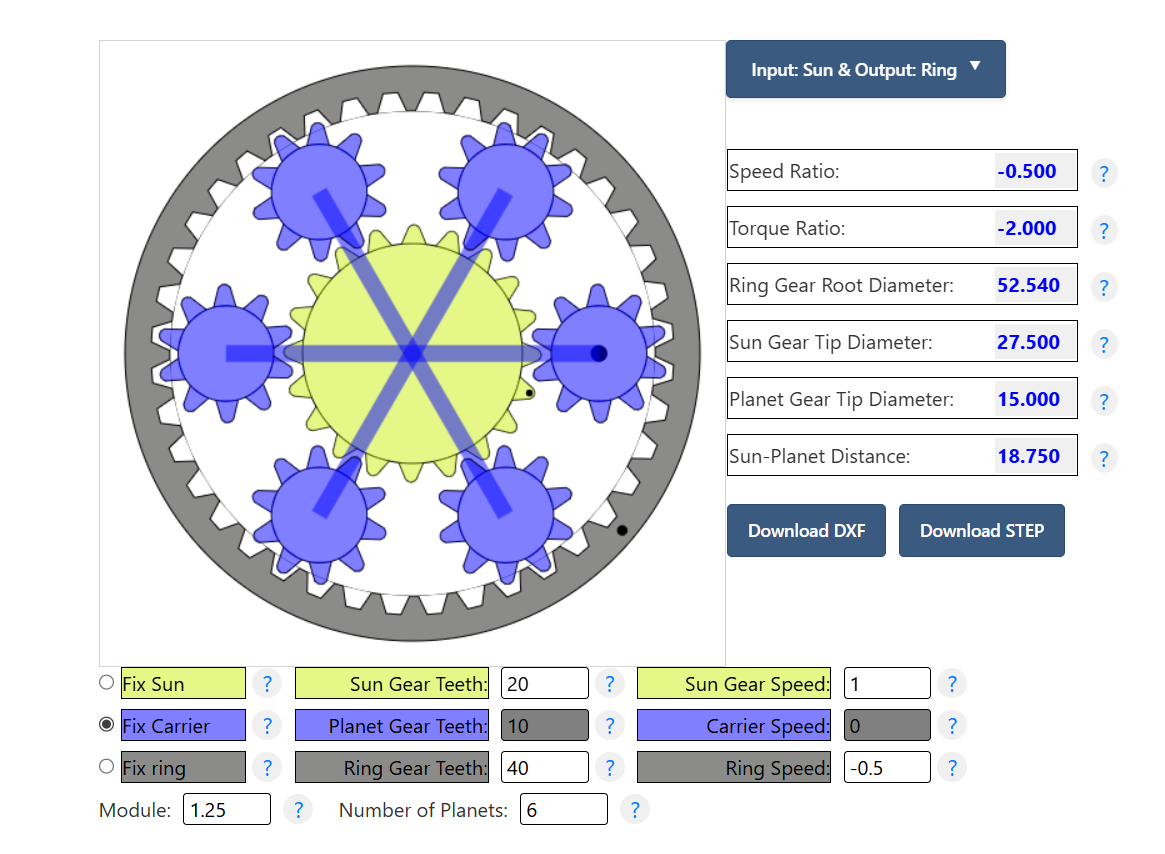
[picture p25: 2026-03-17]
Hardware/Engranaje de Eslabon Brazo 2.png

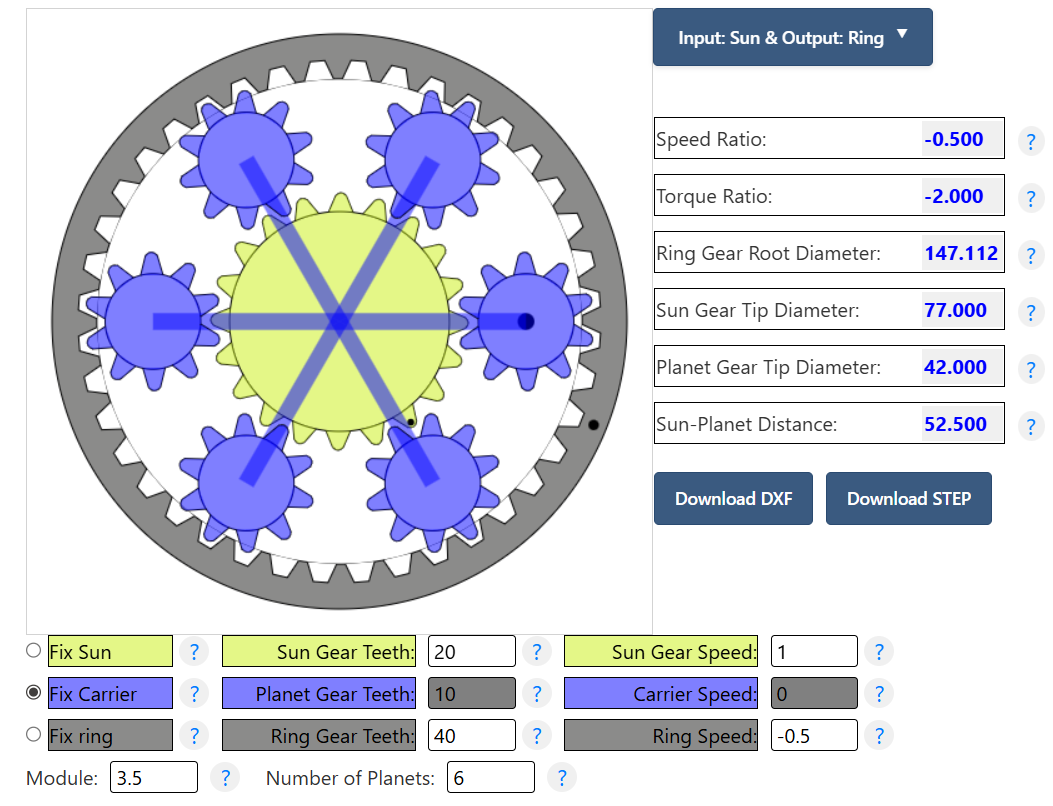
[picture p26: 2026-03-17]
Hardware/Engranaje de Eslabon Base.png

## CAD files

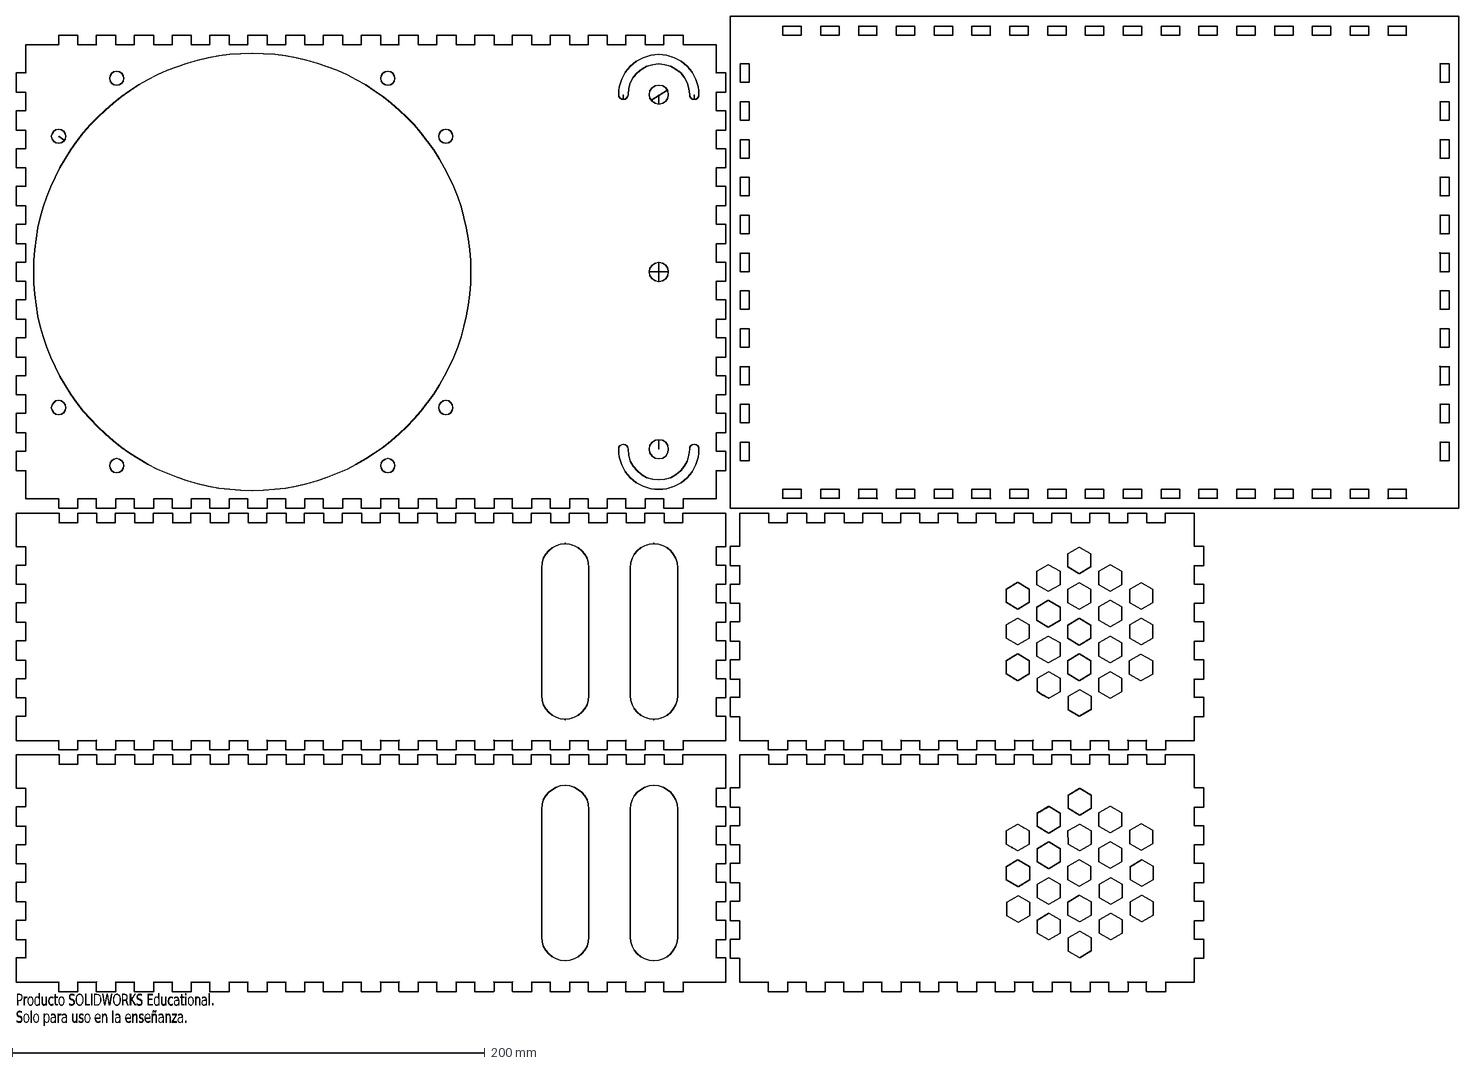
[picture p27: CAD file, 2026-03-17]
Hardware/CAD/BasedBox2.dxf
Producto SOLIDWORKS Educational.
Solo para uso en la enseñanza.

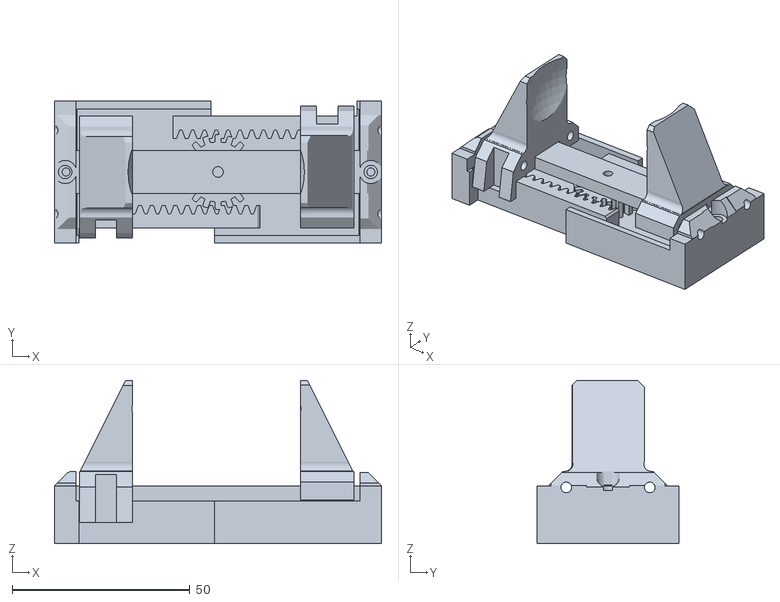
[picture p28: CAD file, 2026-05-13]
Hardware/Gripper/Gripped.stl
92.0 x 40.0 x 46.0

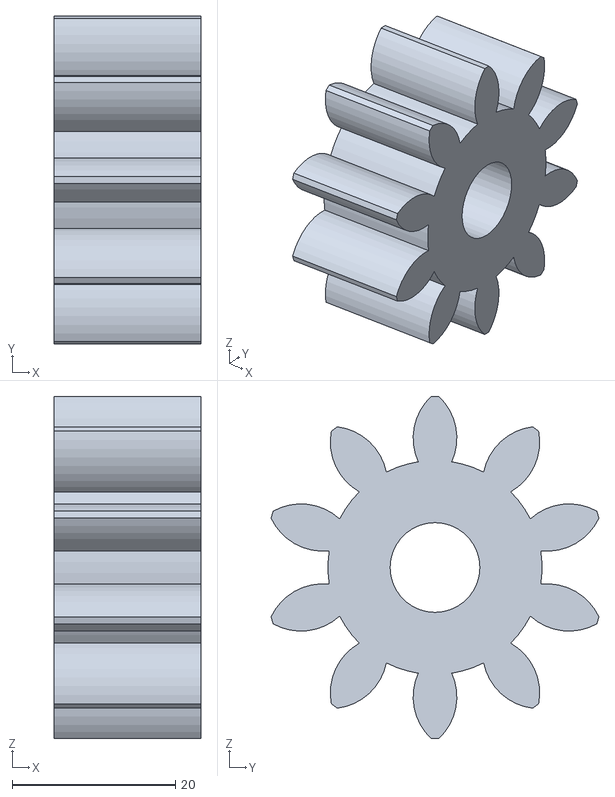
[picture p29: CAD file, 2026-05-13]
Hardware/STLS/Engranes/J1_b1/Planeta.STL
18.0 x 40.2 x 42.0

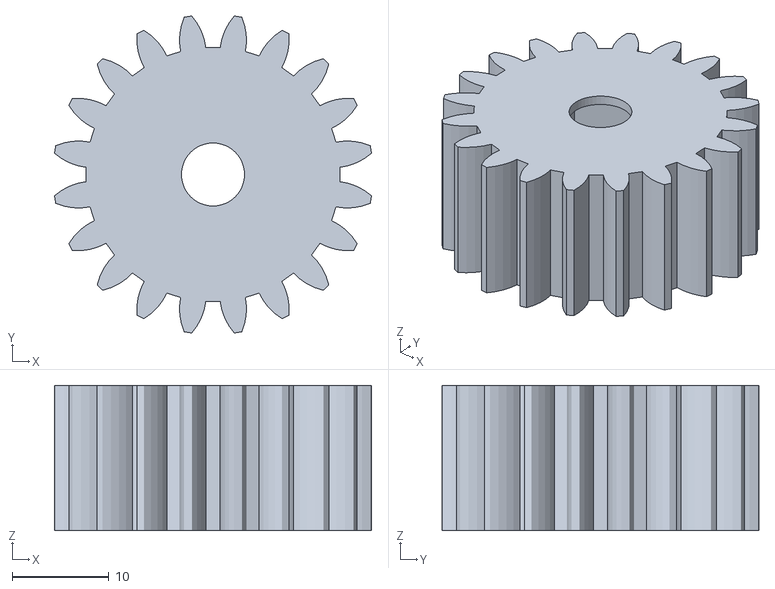
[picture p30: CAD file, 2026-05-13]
Hardware/STLS/Engranes/J2_a1/spur gear_am_shafted_eslave.stl
32.7 x 32.7 x 15.0

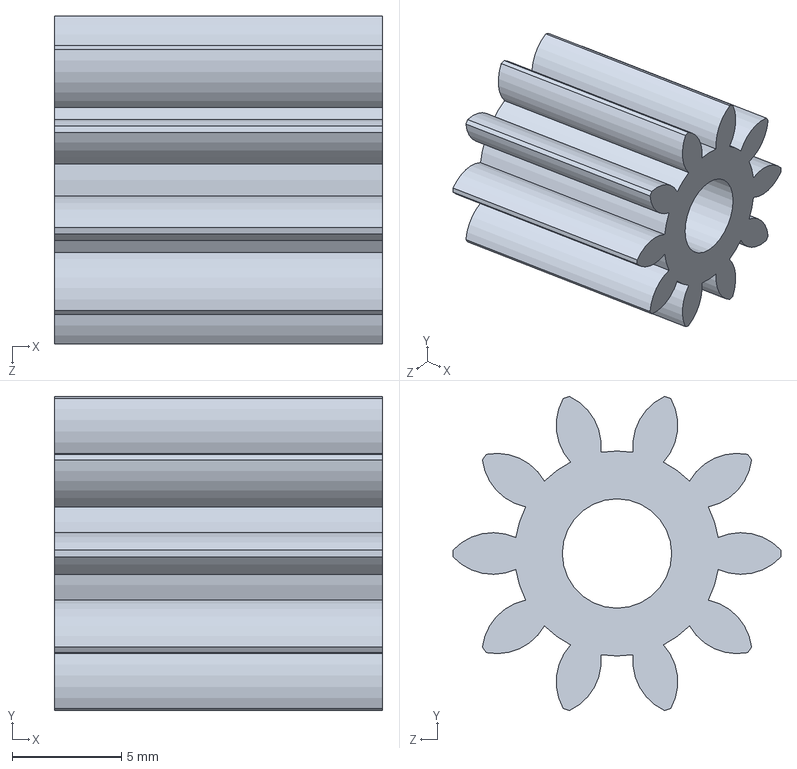
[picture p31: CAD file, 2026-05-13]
Hardware/STLS/Engranes/J3_a2/spur gear_am.SLDPRT
15.0 x 14.4 x 15.0 mm

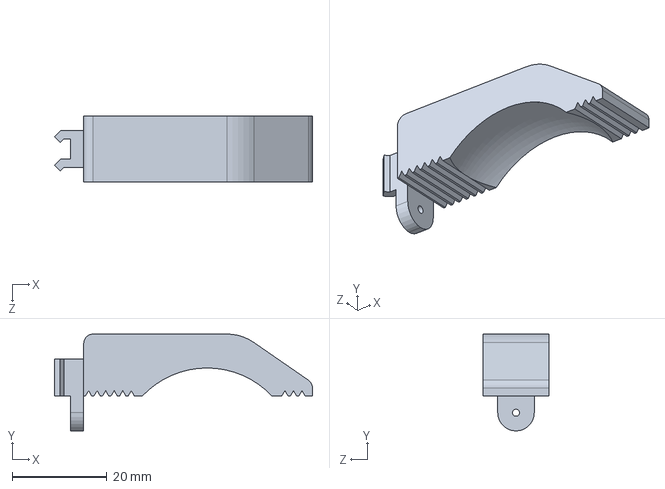
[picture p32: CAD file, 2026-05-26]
Hardware/STLS/Gripper/New_Grip/grid.SLDPRT
54.4 x 20.4 x 14.0 mm

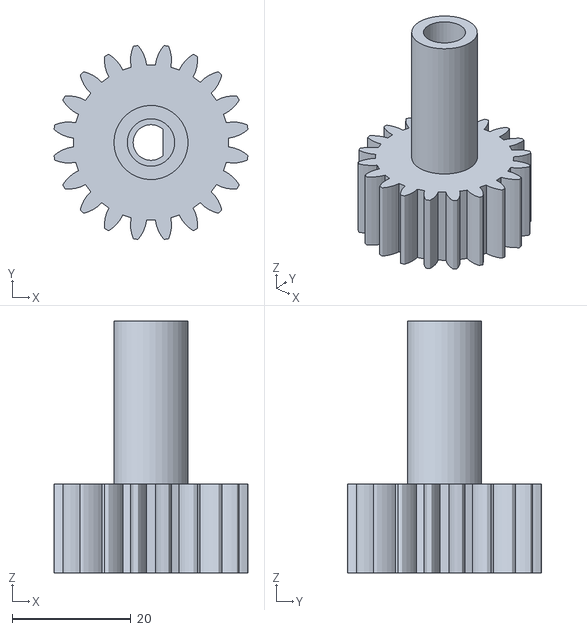
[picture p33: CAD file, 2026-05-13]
Hardware/STLS/J2_a1/spur gear_am_shafted.stl
32.7 x 32.7 x 42.5

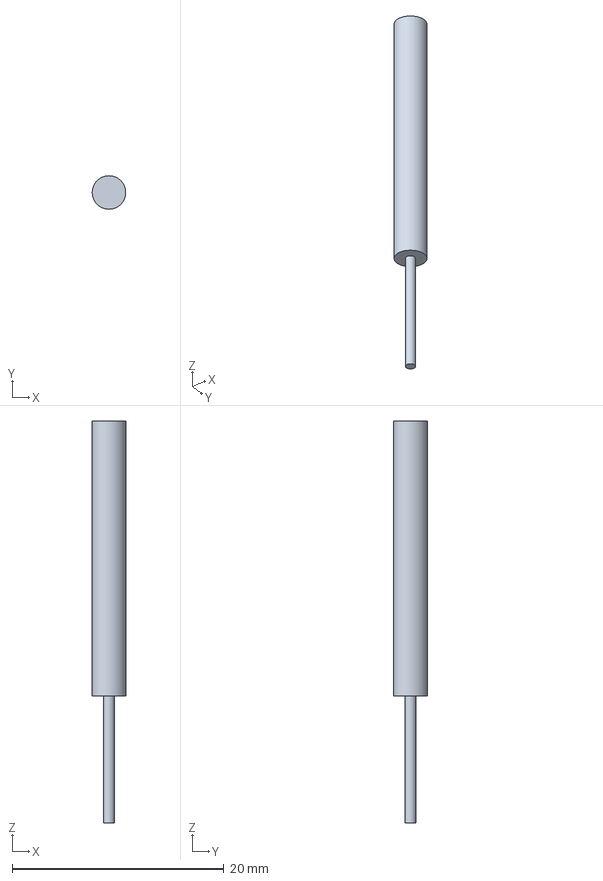
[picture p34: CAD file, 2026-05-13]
Hardware/STLS/J3_a2/Sin nombre.FCStd
3.17 x 3.17 x 38.0 mm

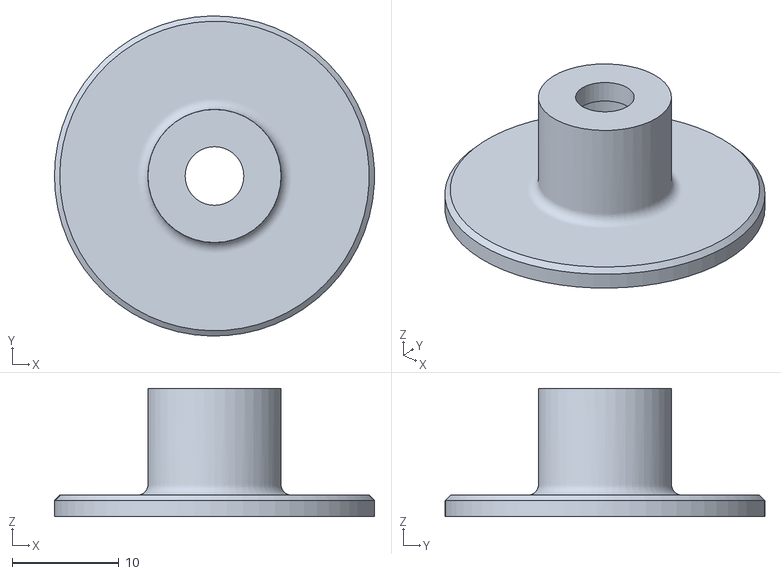
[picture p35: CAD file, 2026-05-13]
Hardware/STLS/tapa2.STL
30.0 x 30.0 x 12.0

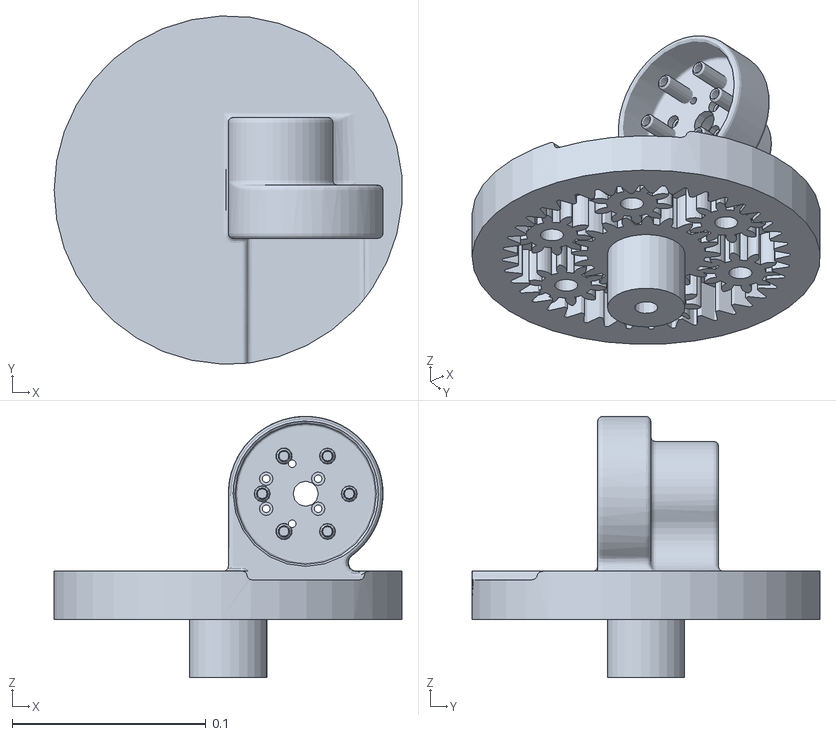
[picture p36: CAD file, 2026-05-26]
Software/brazo_robot/ass12/src/asse12/meshes/collision/B1.STL
0.18 x 0.18 x 0.135

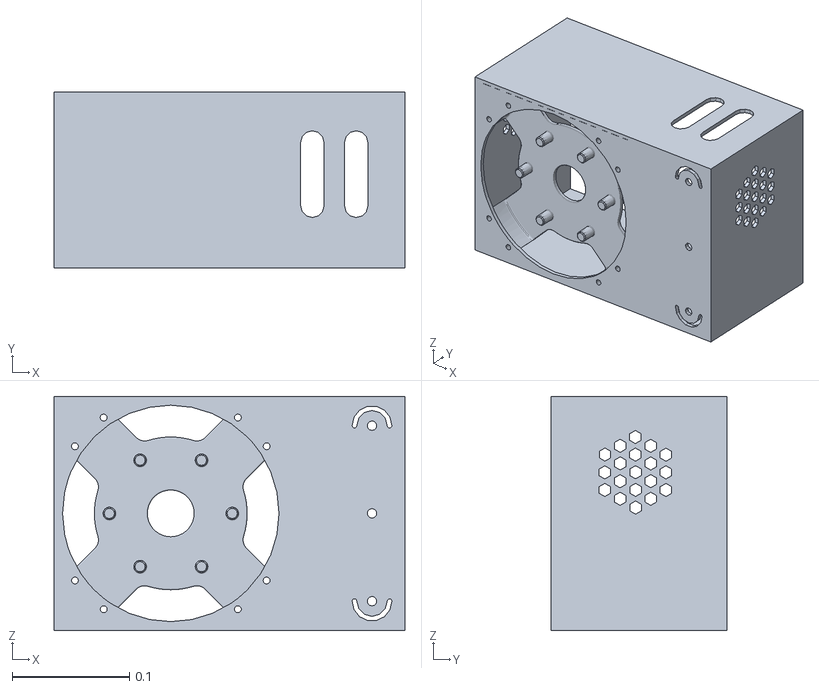
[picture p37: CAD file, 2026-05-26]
Software/brazo_robot/ass12/src/asse12/meshes/visual/base_link.STL
0.3 x 0.15 x 0.2

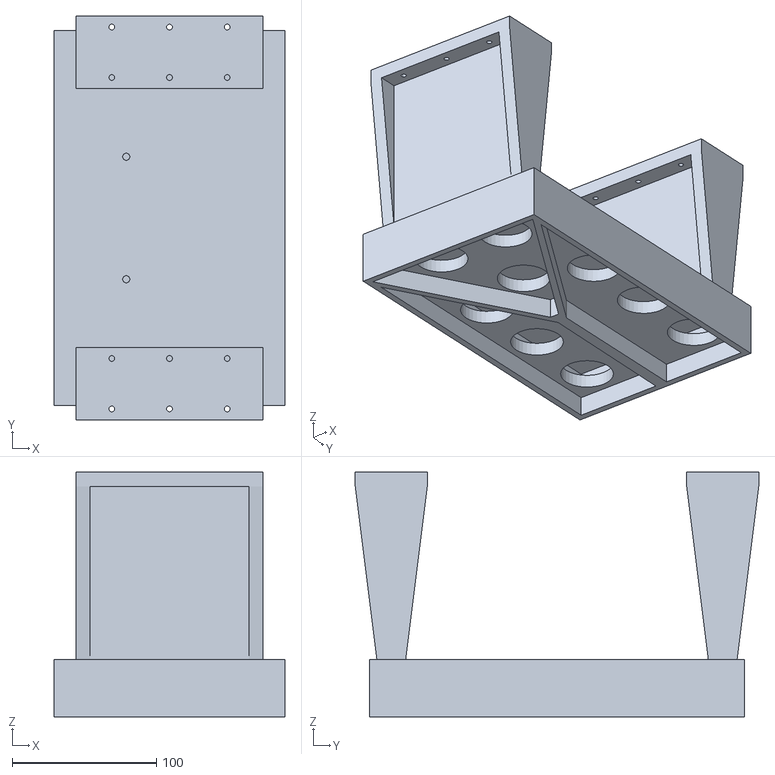
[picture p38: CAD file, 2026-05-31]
Software/brazo_robot/Baseepin.STL
160.0 x 280.0 x 170.0

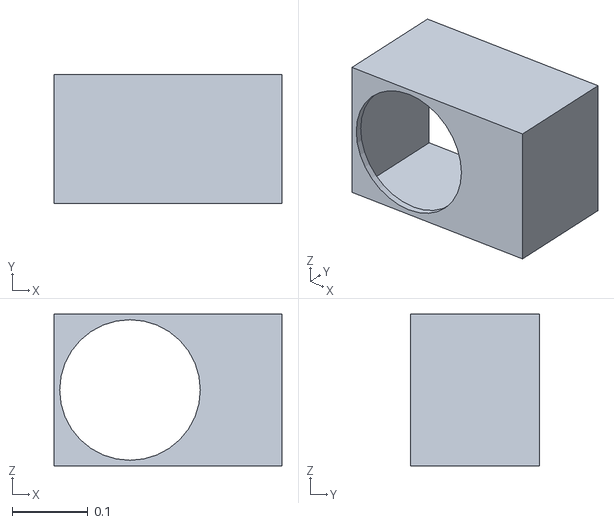
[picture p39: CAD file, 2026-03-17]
Software/Gazebo/ass6/src/asse6/meshes/collision/base_link.STL
0.3 x 0.17 x 0.2

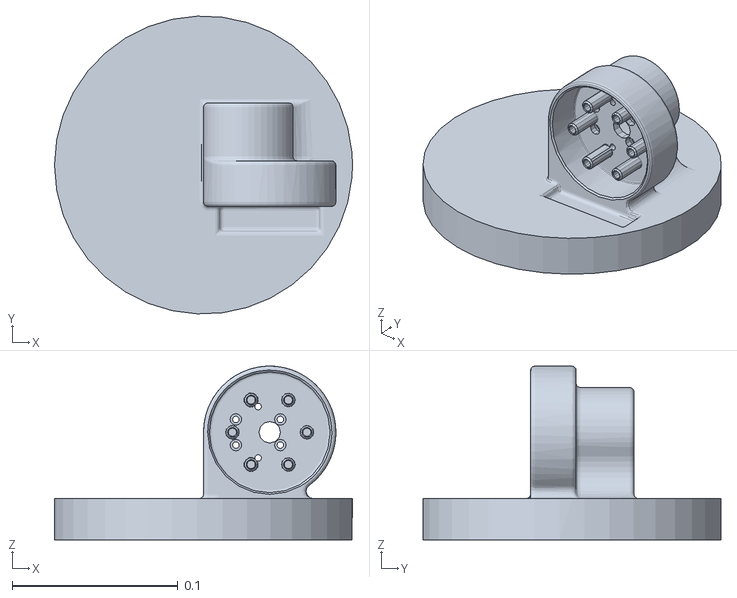
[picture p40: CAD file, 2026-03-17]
Software/Gazebo/ass6/src/asse6/meshes/visual/BaseR.STL
0.18 x 0.18 x 0.105

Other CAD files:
Hardware/STLS/J1_b1/Planet.SLDPRT
Software/Gazebo/Ensamblajefullv6/meshes/Arm1.STL
Hardware/STLs/Ebrazov2.STL
Hardware/STLS/Engranes/J1_b1/sunset.STL
Hardware/STLS/Ebrazov3.STL
Hardware/STLS/Engranes/J1_b1/Planet.SLDPRT
Hardware/STLS/Engranes/J1_b1/sun.SLDPRT
Hardware/STLS/Engranes/J2_a1/spur gear_am.STL
Hardware/STLS/Engranes/J2_a1/spur gear_am8.5.stl
Hardware/STLS/Engranes/J2_a1/spur gear_am9.stl
Hardware/STLS/Engranes/J2_a1/spur gear_am_shaft.SLDPRT
Hardware/STLS/Engranes/J2_a1/spur gear_am_shaft.SLDPRT.STL
Hardware/STLS/Engranes/J3_a2/spur gear_am.STL
Hardware/STLS/Engranes/J3_a2/spur gear_am_shft.SLDPRT
Hardware/STLS/Engranes/J3_a2/spur gear_am_shft.STL
Hardware/STLS/Engranes/J3_a2/spur gear_am_shft_eslave.stl
Hardware/STLS/GearedArm1v2.STL
Hardware/STLS/GearedArm1v2_alt.STL
Hardware/STLS/Gripper/New_Grip/base.SLDPRT
Hardware/STLS/Gripper/New_Grip/base_.STL
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

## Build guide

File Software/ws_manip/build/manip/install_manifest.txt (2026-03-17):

/home/arlo/ws_manip/install/manip/share/manip/launch/display.launch.py
/home/arlo/ws_manip/install/manip/share/manip/urdf/model.urdf
/home/arlo/ws_manip/install/manip/share/manip/urdf/modelold.urdf
/home/arlo/ws_manip/install/manip/share/ament_index/resource_index/package_run_dependencies/manip
/home/arlo/ws_manip/install/manip/share/ament_index/resource_index/parent_prefix_path/manip
/home/arlo/ws_manip/install/manip/share/manip/environment/ament_prefix_path.sh
/home/arlo/ws_manip/install/manip/share/manip/environment/ament_prefix_path.dsv
/home/arlo/ws_manip/install/manip/share/manip/environment/path.sh
/home/arlo/ws_manip/install/manip/share/manip/environment/path.dsv
/home/arlo/ws_manip/install/manip/share/manip/local_setup.bash
/home/arlo/ws_manip/install/manip/share/manip/local_setup.sh
/home/arlo/ws_manip/install/manip/share/manip/local_setup.zsh
/home/arlo/ws_manip/install/manip/share/manip/local_setup.dsv
/home/arlo/ws_manip/install/manip/share/manip/package.dsv
/home/arlo/ws_manip/install/manip/share/ament_index/resource_index/packages/manip
/home/arlo/ws_manip/install/manip/share/manip/cmake/manipConfig.cmake
/home/arlo/ws_manip/install/manip/share/manip/cmake/manipConfig-version.cmake
/home/arlo/ws_manip/install/manip/share/manip/package.xml

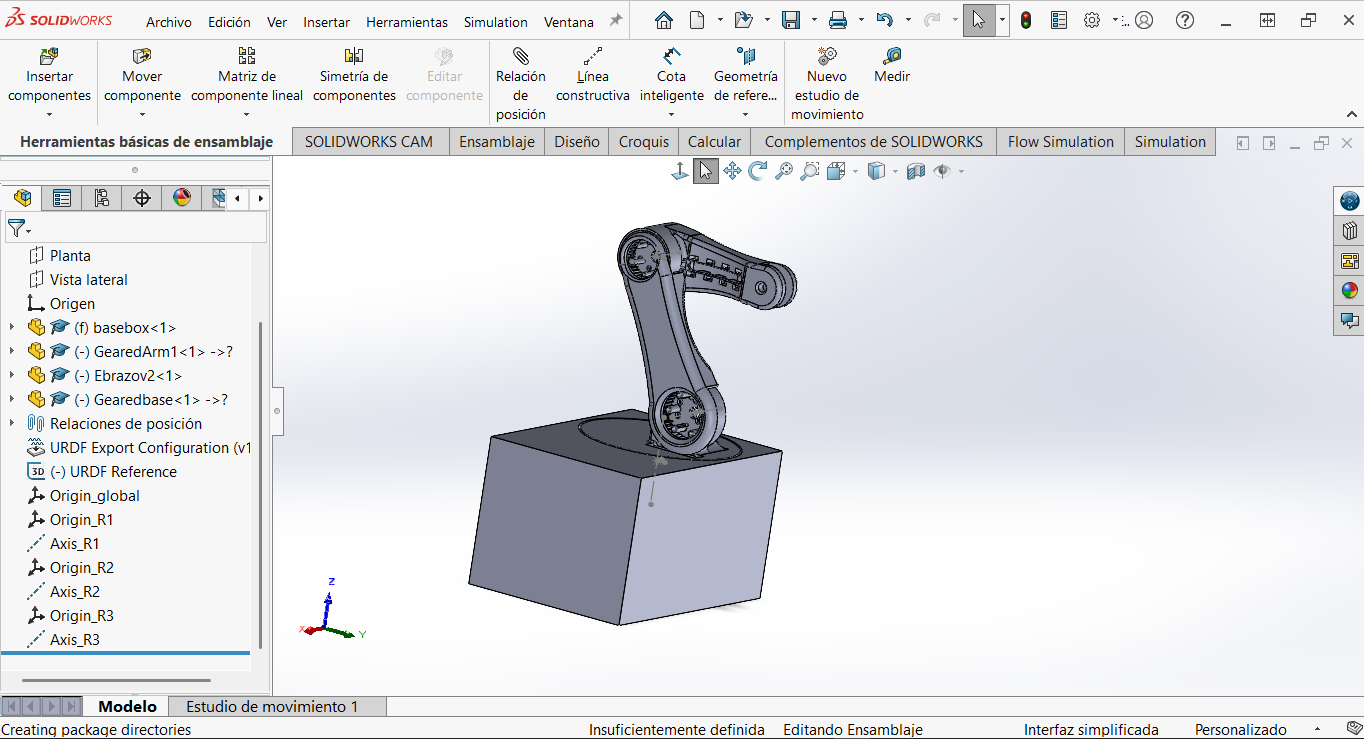
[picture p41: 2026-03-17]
Resources/Ensamblaje 1.png

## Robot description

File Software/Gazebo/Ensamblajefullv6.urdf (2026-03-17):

<?xml version="1.0" encoding="utf-8"?>
<!-- This URDF was automatically created by SolidWorks to URDF Exporter! Originally created by Stephen Brawner (brawner@gmail.com) 
     Commit Version: 1.6.0-4-g7f85cfe  Build Version: 1.6.7995.38578
     For more information, please see http://wiki.ros.org/sw_urdf_exporter -->
<robot name="Ensamblajefullv6">
  <link name="world"/>
  <joint name="world_to_base" type="fixed">
    <parent link="world"/>
    <child link="base_link"/>
    <origin xyz="0 0 -1" rpy="-1.5708 0 0"/>
  </joint>
  <link name="base_link">
    <inertial>
      <origin xyz="0.012565 -0.015002 1.115" rpy="0 0 0" />
      <mass value="3" />
      <inertia ixx="0.007227" ixy="-9.6647E-18" ixz="-0.00067265" iyy="0.011719" iyz="-4.1083E-18" izz="0.014099" />
    </inertial>
    <visual>
      <origin xyz="0 0 0" rpy="0 0 0" />
      <geometry>
        <mesh filename="package://asse6/meshes/visual/base_link.STL" />
      </geometry>
      <material name="">
        <color rgba="0.79216 0.81961 0.93333 1" />
      </material>
    </visual>
    <collision>
      <origin xyz="0 0 0" rpy="0 0 0" />
      <geometry>
        <mesh filename="package://asse6/meshes/visual/base_link.STL" />
      </geometry>
    </collision>
  </link>
  <link name="BaseR">
    <inertial>
      <origin xyz="0.0078866 0.0026077 0.02651" rpy="0 0 0" />
      <mass value="0.25" />
      <inertia ixx="0.0011673" ixy="-1.5261E-05" ixz="-0.00011283" iyy="0.0012563" iyz="-2.409E-05" izz="0.0019548" />
    </inertial>
    <visual>
      <origin xyz="0 0 0" rpy="0 0 0" />
      <geometry>
        <mesh filename="package://asse6/meshes/visual/BaseR.STL" />
      </geometry>
      <material name="">
        <color rgba="0.79216 0.81961 0.93333 1" />
      </material>
    </visual>
    <collision>
      <origin xyz="0 0 0" rpy="0 0 0" />
      <geometry>
        <mesh filename="package://asse6/meshes/visual/BaseR.STL" />
      </geometry>
    </collision>
  </link>
  <joint name="R1" type="continuous">
    <origin xyz="-0.0541212640299427 -1.14500000000001 -0.0150018955467125" rpy="1.57079632679489 -1.56377472859413 0" />
    <parent link="base_link" />
    <child link="BaseR" />
    <axis xyz="0 0 1" />
  </joint>
  <link name="Arm1">
    <inertial>
      <origin xyz="-0.020414 -6.1851E-05 0.082682" rpy="0 0 0" />
      <mass value="0.15" />
      <inertia ixx="0.0010516" ixy="1.5848E-07" ixz="-1.1229E-05" iyy="0.00096052" iyz="1.6129E-07" izz="0.00013862" />
    </inertial>
    <visual>
      <origin xyz="0 0 0" rpy="0 0 0" />
      <geometry>
        <mesh filename="package://asse6/meshes/visual/Arm1.STL" />
      </geometry>
      <material name="">
        <color rgba="0.79216 0.81961 0.93333 1" />
      </material>
    </visual>
    <collision>
      <origin xyz="0 0 0" rpy="0 0 0" />
      <geometry>
        <mesh filename="package://asse6/meshes/visual/Arm1.STL" />
      </geometry>
    </collision>
  </link>
  <joint name="R2" type="continuous">
    <origin xyz="0.0400000000000003 0 0.0649999999999988" rpy="-0.470162054989727 0 1.5707963267949" />
    <parent link="BaseR" />
    <child link="Arm1" />
    <axis xyz="1 0 0" />
  </joint>
  <link name="Arm2">
    <inertial>
      <origin xyz="2.4367E-06 0.052614 0.02152" rpy="0 0 0" />
      <mass value="0.1" />
      <inertia ixx="0.00091559" ixy="-1.7395E-08" ixz="4.0709E-09" iyy="0.00015629" iyz="-4.3557E-05" izz="0.00095733" />
    </inertial>
    <visual>
      <origin xyz="0 0 0" rpy="0 0 0" />
      <geometry>
        <mesh filename="package://asse6/meshes/visual/Arm2.STL" />
      </geometry>
      <material name="">
        <color rgba="0.79216 0.81961 0.93333 1" />
      </material>
    </visual>
    <collision>
      <origin xyz="0 0 0" rpy="0 0 0" />
      <geometry>
        <mesh filename="package://asse6/meshes/visual/Arm2.STL" />
      </geometry>
    </collision>
  </link>
  <joint name="R3" type="continuous">
    <origin xyz="0 0 0.18" rpy="-1.5708 -1.0832 -1.5708" />
    <parent link="Arm1" />
    <child link="Arm2" />
    <axis xyz="0 0 1" />
  </joint>
</robot>

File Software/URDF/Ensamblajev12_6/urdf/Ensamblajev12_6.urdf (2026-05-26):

<?xml version="1.0" encoding="utf-8"?>
<!-- This URDF was automatically created by SolidWorks to URDF Exporter! Originally created by Stephen Brawner (brawner@gmail.com) 
     Commit Version: 1.6.0-4-g7f85cfe  Build Version: 1.6.7995.38578
     For more information, please see http://wiki.ros.org/sw_urdf_exporter -->
<robot name="Ensamblajev12_6">
  <link name="base_link">
    <inertial>
      <origin xyz="0.14769 -0.092824 0.09895" rpy="0 0 0" />
      <mass value="5" />
      <inertia ixx="0.0061943" ixy="0.00034463" ixz="-2.711E-05" iyy="0.013162" iyz="9.2508E-06" izz="0.010154" />
    </inertial>
    <visual>
      <origin xyz="0 0 0" rpy="0 0 0" />
      <geometry>
        <mesh filename="package://Ensamblajev12_6/meshes/base_link.STL" />
      </geometry>
      <material name="">
        <color rgba="0.29804 0.29804 0.29804 1" />
      </material>
    </visual>
    <collision>
      <origin xyz="0 0 0" rpy="0 0 0" />
      <geometry>
        <mesh filename="package://Ensamblajev12_6/meshes/base_link.STL" />
      </geometry>
    </collision>
  </link>
  <link name="B1">
    <inertial>
      <origin xyz="0.0050893 0.0028829 0.020526" rpy="0 0 0" />
      <mass value="0.2" />
      <inertia ixx="0.0011773" ixy="-3.3249E-05" ixz="-0.00011396" iyy="0.0012987" iyz="-2.1578E-05" izz="0.0019641" />
    </inertial>
    <visual>
      <origin xyz="0 0 0" rpy="0 0 0" />
      <geometry>
        <mesh filename="package://Ensamblajev12_6/meshes/B1.STL" />
      </geometry>
      <material name="">
        <color rgba="1 1 1 1" />
      </material>
    </visual>
    <collision>
      <origin xyz="0 0 0" rpy="0 0 0" />
      <geometry>
        <mesh filename="package://Ensamblajev12_6/meshes/B1.STL" />
      </geometry>
    </collision>
  </link>
  <joint name="J1" type="continuous">
    <origin xyz="0.099806 -0.135 0.10018" rpy="1.5708 -0.0014338 0" />
    <parent link="base_link" />
    <child link="B1" />
    <axis xyz="0 0 1" />
  </joint>
  <link name="A1">
    <inertial>
      <origin xyz="0.084043 0.00053774 0.011617" rpy="0 0 0" />
      <mass value="0.15" />
      <inertia ixx="0.00014704" ixy="-6.8149E-06" ixz="-3.9771E-06" iyy="0.0013021" iyz="-1.488E-07" izz="0.0013966" />
    </inertial>
    <visual>
      <origin xyz="0 0 0" rpy="0 0 0" />
      <geometry>
        <mesh filename="package://Ensamblajev12_6/meshes/A1.STL" />
      </geometry>
      <material name="">
        <color rgba="1 1 1 1" />
      </material>
    </visual>
    <collision>
      <origin xyz="0 0 0" rpy="0 0 0" />
      <geometry>
        <mesh filename="package://Ensamblajev12_6/meshes/A1.STL" />
      </geometry>
    </collision>
  </link>
  <joint name="J2" type="continuous">
    <origin xyz="0.04 -0.032 0.065" rpy="-1.5708 0 -0.0014338" />
    <parent link="B1" />
    <child link="A1" />
    <axis xyz="-0.0014338 0 1" />
    <limit lower="-2.43" upper="0" effort="10" velocity="1" />
  </joint>
  <link name="A2">
    <inertial>
      <origin xyz="0.0040691 0.05438 0.044947" rpy="0 0 0" />
      <mass value="0.1" />
      <inertia ixx="0.00089175" ixy="-3.5921E-05" ixz="-1.9369E-06" iyy="0.00015707" iyz="-3.9437E-05" izz="0.00093244" />
    </inertial>
    <visual>
      <origin xyz="0 0 0" rpy="0 0 0" />
      <geometry>
        <mesh filename="package://Ensamblajev12_6/meshes/A2.STL" />
      </geometry>
      <material name="">
        <color rgba="1 1 1 1" />
      </material>
    </visual>
    <collision>
      <origin xyz="0 0 0" rpy="0 0 0" />
      <geometry>
        <mesh filename="package://Ensamblajev12_6/meshes/A2.STL" />
      </geometry>
    </collision>
  </link>
  <joint name="J3" type="continuous">
    <origin xyz="0.17997 0.0027028 0.0072582" rpy="0.0014338 -1.051E-05 -1.5635" />
    <parent link="A1" />
    <child link="A2" />
    <axis xyz="0 0 1" />
    <limit lower="-2.68" upper="2.88" effort="10" velocity="1" />
  </joint>
  <link name="G1">
    <inertial>
      <origin xyz="-0.006216 0.0025049 0.0077751" rpy="0 0 0" />
      <mass value="0.005" />
      <inertia ixx="1.0619E-09" ixy="-5.2811E-10" ixz="-1.0382E-11" iyy="1.8409E-08" iyz="2.1736E-11" izz="1.7847E-08" />
    </inertial>
    <visual>
      <origin xyz="0 0 0" rpy="0 0 0" />
      <geometry>
        <mesh filename="package://Ensamblajev12_6/meshes/G1.STL" />
      </geometry>
      <material name="">
        <color rgba="1 1 1 1" />
      </material>
    </visual>
    <collision>
      <origin xyz="0 0 0" rpy="0 0 0" />
      <geometry>
        <mesh filename="package://Ensamblajev12_6/meshes/G1.STL" />
      </geometry>
    </collision>
  </link>
  <joint name="J4" type="fixed">
    <origin xyz="-0.00025 0.16894 0.047" rpy="-3.1416 0.89637 -3.1416" />
    <parent link="A2" />
    <child link="G1" />
    <axis xyz="0 1 0" />
    <limit lower="0" upper="0" effort="0" velocity="0" />
  </joint>
  <link name="g11">
    <inertial>
      <origin xyz="-0.00056573 0.013666 -0.010485" rpy="0 0 0" />
      <mass value="0.001" />
      <inertia ixx="1.3061E-06" ixy="4.6516E-08" ixz="-5.928E-10" iyy="1.8437E-07" iyz="1.4324E-08" izz="1.32E-06" />
    </inertial>
    <visual>
      <origin xyz="0 0 0" rpy="0 0 0" />
      <geometry>
        <mesh filename="package://Ensamblajev12_6/meshes/g11.STL" />
      </geometry>
      <material name="">
        <color rgba="1 1 1 1" />
      </material>
    </visual>
    <collision>
      <origin xyz="0 0 0" rpy="0 0 0" />
      <geometry>
        <mesh filename="package://Ensamblajev12_6/meshes/g11.STL" />
      </geometry>
    </collision>
  </link>
  <joint name="g1" type="prismatic">
    <origin xyz="-0.025731 0.0086004 -0.0071255" rpy="0.0091681 0.89634 0.011738" />
    <parent link="G1" />
    <child link="g11" />
    <axis xyz="0 0 1" />
    <limit lower="-0.01" upper="0.02" effort="10" velocity="1" />
    <mimic joint="J4" multiplier="1" offset="0" />
  </joint>
  <link name="g12">
    <inertial>
      <origin xyz="-0.00056572 0.013666 0.010485" rpy="0 0 0" />
      <mass value="0.001" />
      <inertia ixx="1.3061E-06" ixy="4.6515E-08" ixz="5.931E-10" iyy="1.8437E-07" iyz="-1.4324E-08" izz="1.32E-06" />
    </inertial>
    <visual>
      <origin xyz="0 0 0" rpy="0 0 0" />
      <geometry>
        <mesh filename="package://Ensamblajev12_6/meshes/g12.STL" />
      </geometry>
      <material name="">
        <color rgba="1 1 1 1" />
      </material>
    </visual>
    <collision>
      <origin xyz="0 0 0" rpy="0 0 0" />
      <geometry>
        <mesh filename="package://Ensamblajev12_6/meshes/g12.STL" />
      </geometry>
    </collision>
  </link>
  <joint name="g2" type="prismatic">
    <origin xyz="0.012167 0.0085931 0.023365" rpy="0.0091681 0.89634 0.011738" />
    <parent link="G1" />
    <child link="g12" />
    <axis xyz="0 0 -1" />
    <limit lower="-0.01" upper="0.025" effort="10" velocity="1" />
    <mimic joint="g1" multiplier="1" offset="0" />
  </joint>
</robot>

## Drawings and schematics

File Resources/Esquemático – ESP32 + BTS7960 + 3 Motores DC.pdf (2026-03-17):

⚡ ESQUEMÁTICO — ESP32 · BTS7960 × 3 · Motores DC · IMU | Rev 2.0 | BTS7960 Half-Bridge Driver

# FUENTE 12V DC

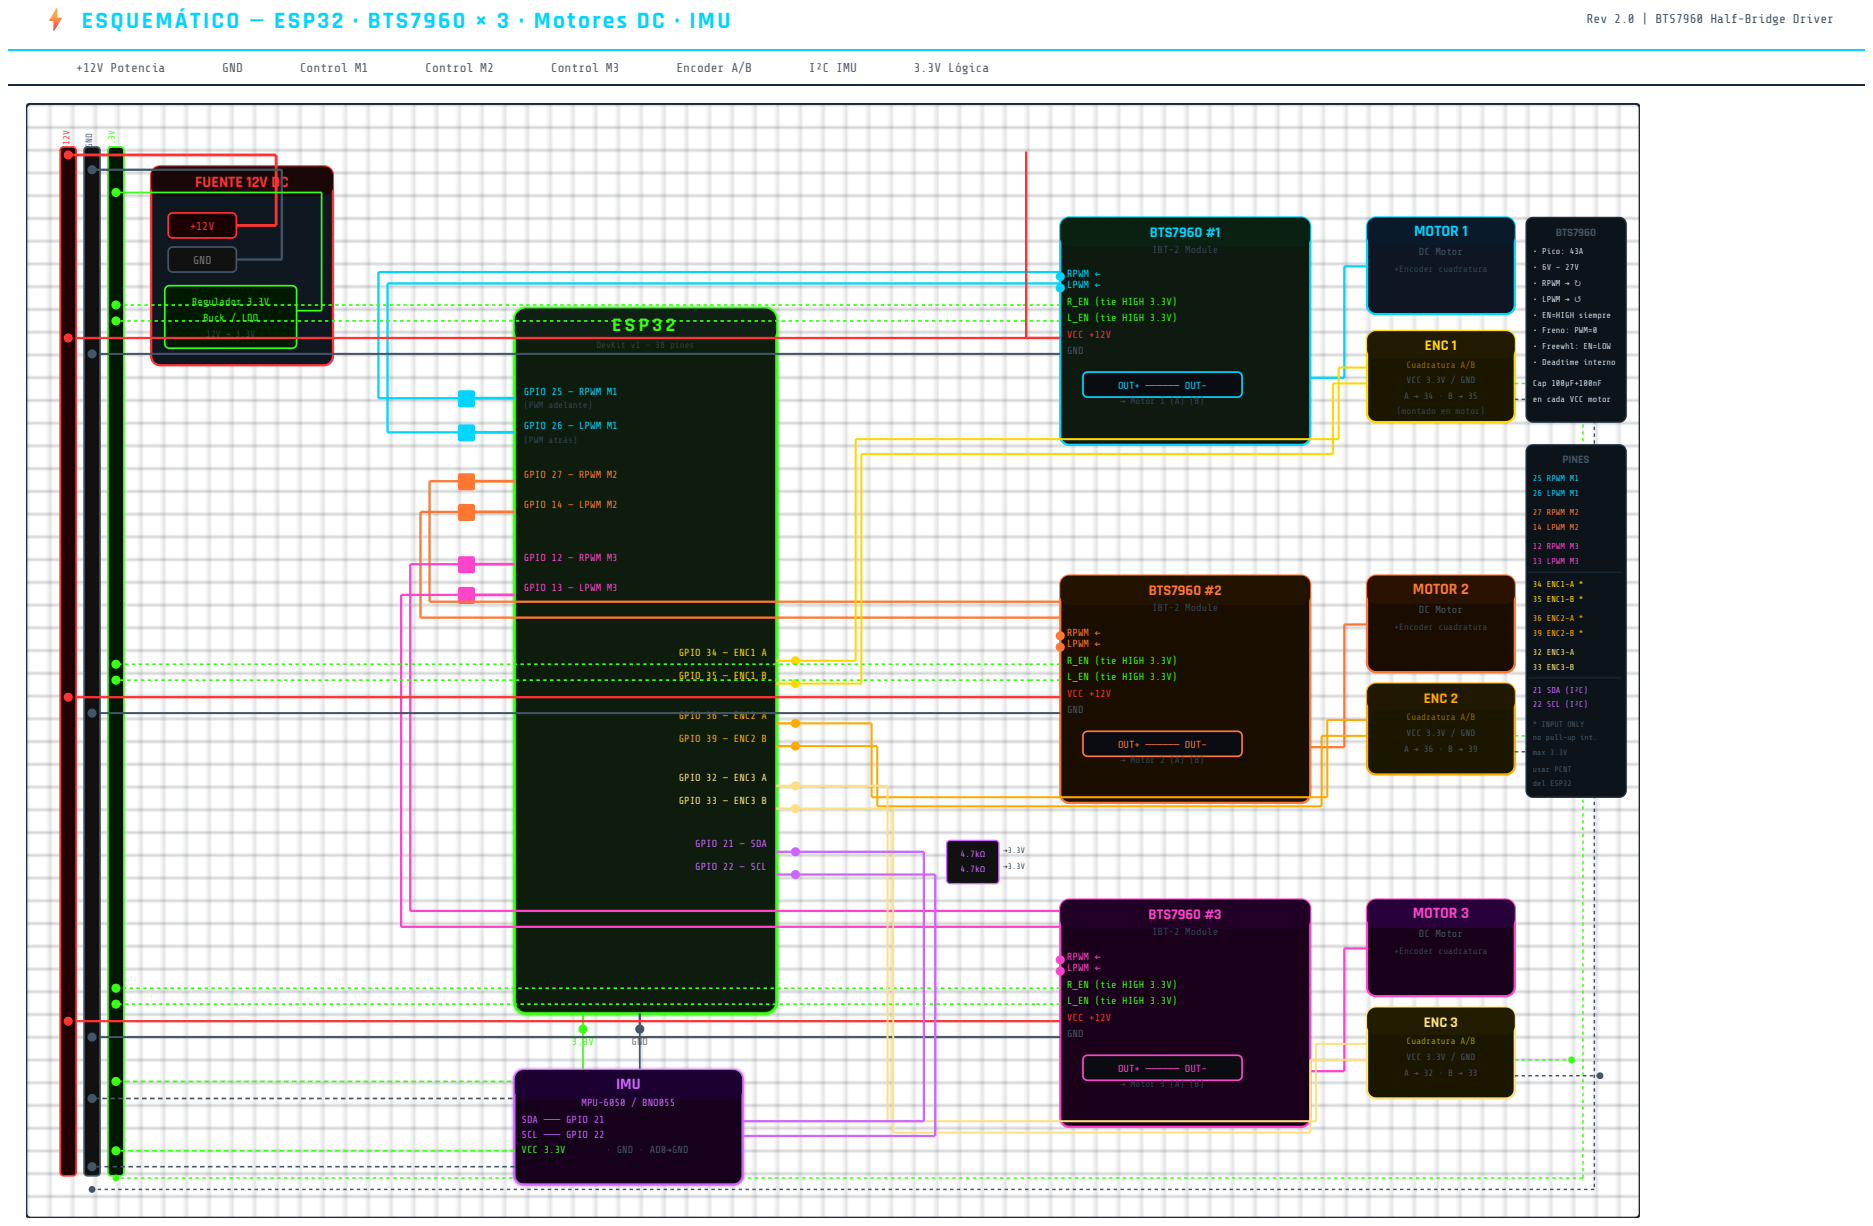
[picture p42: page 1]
+12V Potencia; GND; Control M1; Control M2; Control M3; Encoder A/B; I²C IMU; 3.3V Lógica; Regulador 3.3V Buck / LDO; DevKit v1 — 38 pines; GPIO 25 — RPWM M1 (PWM adelante); GPIO 26 — LPWM M1 (PWM atrás); GPIO 27 — RPWM M2; GPIO 14 — LPWM M2; GPIO 12 — RPWM M3; GPIO 13 — LPWM M3; GPIO 34 — ENC1 A; GPIO 35 — ENC1 B; GPIO 36 — ENC2 A; GPIO 39 — ENC2 B; GPIO 32 — ENC3 A; GPIO 33 — ENC3 B; GPIO 21 — SDA; GPIO 22 — SCL; BTS7960 #1; IBT-2 Module; RPWM ← LPWM ←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

• Pico: 43A
• RPWM → ↻
• LPWM → ↺
• EN=HIGH siempre
• Freno: PWM=0
• Freewhl: EN=LOW
• Deadtime interno

Cuadratura A/B
VCC 3.3V / GND
(montado en motor)

Cap 100µF+100nF
en cada VCC motor

* INPUT ONLY
no pull-up int.
max 3.3V

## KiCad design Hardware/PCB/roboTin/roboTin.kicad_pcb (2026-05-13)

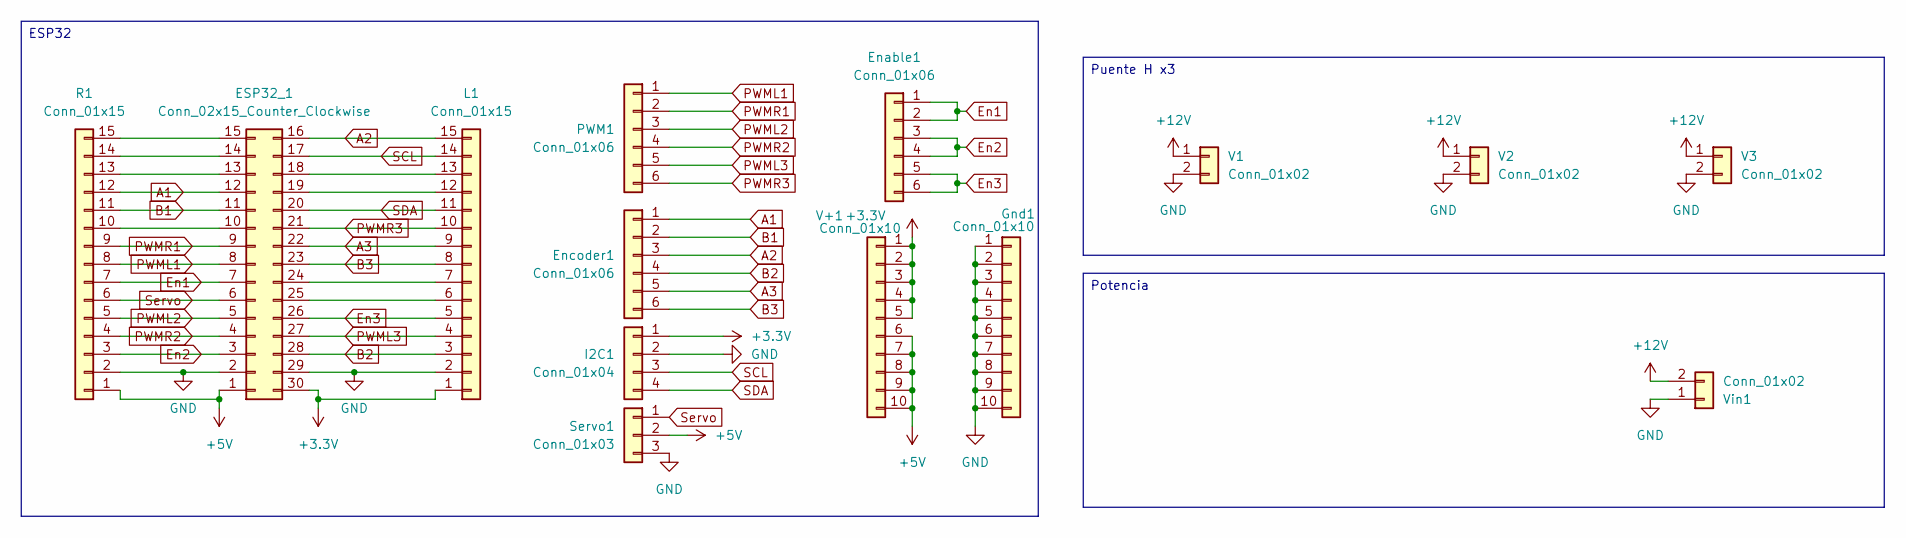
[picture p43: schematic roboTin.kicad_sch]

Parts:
ESP32_1: Conn_02x15_Counter_Clockwise; ESP_Test
Enable1: Conn_01x06; PinHeader_1x06_P2.54mm_Vertical
Encoder1: Conn_01x06; PinHeader_1x06_P2.54mm_Vertical
Gnd1: Conn_01x10; PinHeader_1x10_P2.54mm_Vertical
I2C1: Conn_01x04; PinHeader_1x04_P2.54mm_Vertical
L1: Conn_01x15; PinHeader_1x15_P2.54mm_Vertical
PWM1: Conn_01x06; PinHeader_1x06_P2.54mm_Vertical
R1: Conn_01x15; PinHeader_1x15_P2.54mm_Vertical
Servo1: Conn_01x03; PinHeader_1x03_P2.54mm_Vertical
V1, V2, V3: Conn_01x02; PhoenixContact_MSTBA_2,5_2-G-5,08_1x02_P5.08mm_Horizontal
V+1: Conn_01x10; PinHeader_1x10_P2.54mm_Vertical
Vin1: Conn_01x02; PhoenixContact_MSTBA_2,5_2-G-5,08_1x02_P5.08mm_Horizontal

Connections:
+3.3V: ESP32_1.30, I2C1.1, L1.1, V+1.1, V+1.2, V+1.3, V+1.4, V+1.5
+5V: ESP32_1.1, R1.1, Servo1.2, V+1.6, V+1.7, V+1.8, V+1.9, V+1.10
+12V: V1.1, V2.1, V3.1, Vin1.2
A1: ESP32_1.12, Encoder1.1, R1.12
A2: ESP32_1.16, Encoder1.3, L1.15
A3: ESP32_1.22, Encoder1.5, L1.9
B1: ESP32_1.11, Encoder1.2, R1.11
B2: ESP32_1.28, Encoder1.4, L1.3
B3: ESP32_1.23, Encoder1.6, L1.8
En1: ESP32_1.7, Enable1.1, Enable1.2, R1.7
En2: ESP32_1.3, Enable1.3, Enable1.4, R1.3
En3: ESP32_1.26, Enable1.5, Enable1.6, L1.5
GND: ESP32_1.2, ESP32_1.29, Gnd1.1, Gnd1.2, Gnd1.3, Gnd1.4, Gnd1.5, Gnd1.6, Gnd1.7, Gnd1.8, Gnd1.9, Gnd1.10, I2C1.2, L1.2, R1.2, Servo1.3, V1.2, V2.2, V3.2, Vin1.1
unnamed: ESP32_1.10, R1.10
unnamed: ESP32_1.13, R1.13
unnamed: ESP32_1.14, R1.14
unnamed: ESP32_1.15, R1.15
unnamed: ESP32_1.18, L1.13
unnamed: ESP32_1.19, L1.12
unnamed: ESP32_1.24, L1.7
unnamed: ESP32_1.25, L1.6
PWML1: ESP32_1.8, PWM1.1, R1.8
PWML2: ESP32_1.5, PWM1.3, R1.5
PWML3: ESP32_1.27, L1.4, PWM1.5
PWMR1: ESP32_1.9, PWM1.2, R1.9
PWMR2: ESP32_1.4, PWM1.4, R1.4
PWMR3: ESP32_1.21, L1.10, PWM1.6
SCL: ESP32_1.17, I2C1.3, L1.14
SDA: ESP32_1.20, I2C1.4, L1.11
Servo: ESP32_1.6, R1.6, Servo1.1

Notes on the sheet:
Puente H x3
Potencia
ESP32

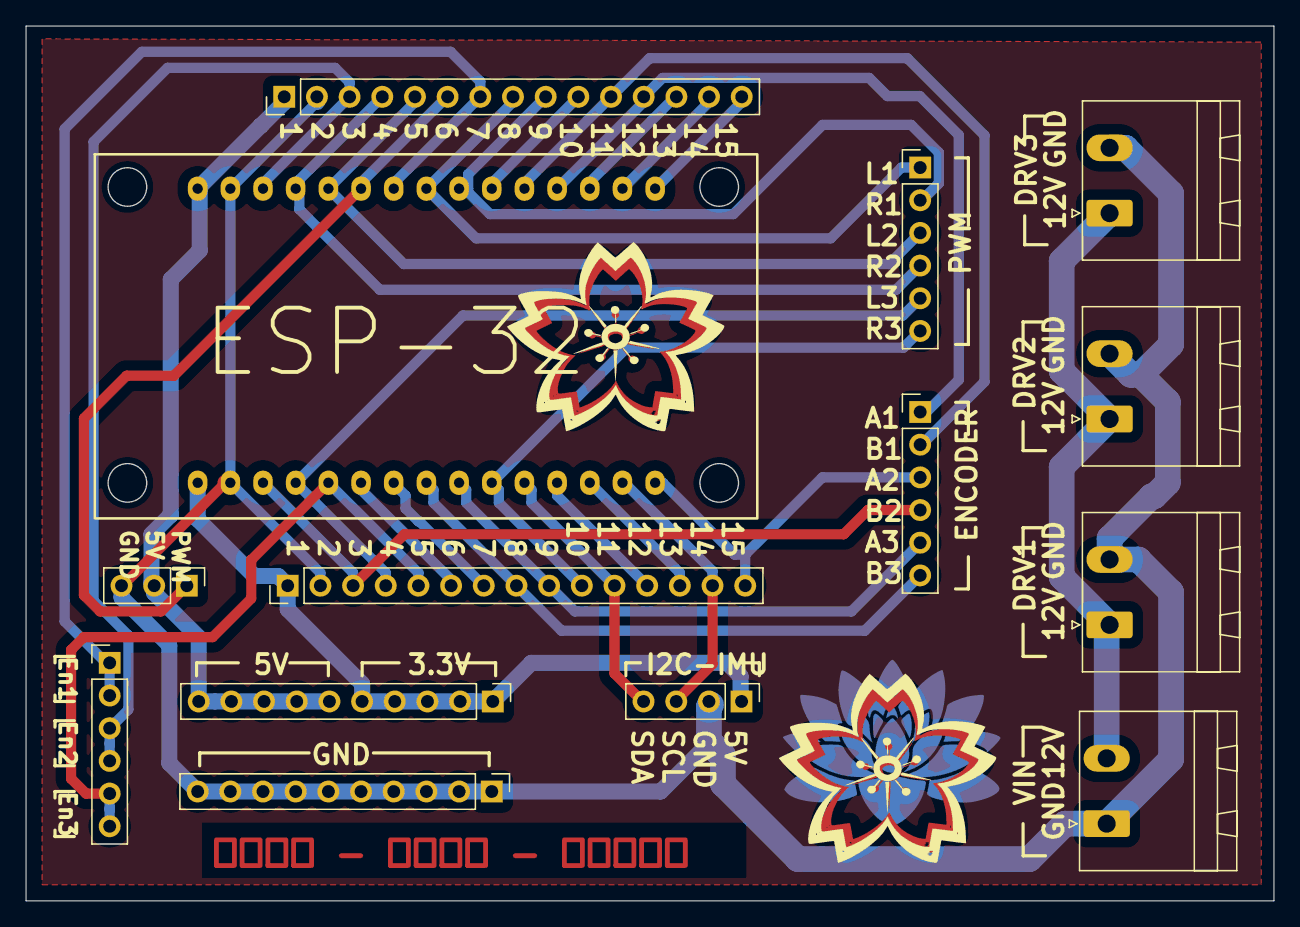
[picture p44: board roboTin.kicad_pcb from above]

Board: 2 copper layers, 97.0 x 68.0 mm, 14 parts (0 on the bottom side), 30 nets.

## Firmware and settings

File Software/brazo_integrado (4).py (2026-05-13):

"""
═══════════════════════════════════════════════════════════════════════════════
  BRAZO ROBÓTICO 3-DOF — SIMULADOR INTEGRADO
  -----------------------------------------------------------------------------
  Pestañas:
    1)  Vista 3D         — Eslabones animados con cinemática directa (DH)
    2)  Motores + PID    — Simulación del lazo de control del firmware .ino
                           (P proporcional con deadband y saturación PWM_MIN/MAX)
    3)  Trayectoria      — Se ingresa una pose final (por ángulos articulares
                           o por coordenadas cartesianas X,Y,Z usando IK
                           analítica) y el brazo se mueve con el perfil
                           quíntico (polinomio grado 5 → velocidad de
                           perfil cúbico: qdd es cúbica en t, jerk finito).
                           Condiciones: q, qd y qdd = 0 en los dos extremos.
  -----------------------------------------------------------------------------
  Parámetros físicos consistentes con los códigos originales:
    DH:      a = [40, 180, 140] mm,  d = [0, 0, 0] mm,  α = [90°, 0°, 0°]
             (a1=40mm: offset horizontal del eje del primer brazo —
              gira con q1, desplazado 40mm del centro de la base)
    PPR:     M1=M2 = 6720 p/rev,  M3 = 8640 p/rev
    PWM:     MIN=60, MAX=180, deadband=20 pulsos
═══════════════════════════════════════════════════════════════════════════════
"""

import tkinter as tk
from tkinter import ttk, messagebox
import numpy as np
import matplotlib
matplotlib.use("TkAgg")
import matplotlib.pyplot as plt
import matplotlib.gridspec as gridspec
from matplotlib.backends.backend_tkagg import FigureCanvasTkAgg
from mpl_toolkits.mplot3d import Axes3D  # noqa: F401  (registro proyección 3D)

# ═══════════════════════════════════════════════════════════════════════════════
#  TEMA VISUAL  (igual al sim_tray.py)
# ═══════════════════════════════════════════════════════════════════════════════
BG       = "#0d1117"
PANEL    = "#161b22"
BORDER   = "#30363d"
TEXT     = "#c9d1d9"
ACCENT   = "#f0f6fc"
MUTED    = "#8b949e"
BTN_BG   = "#21262d"
BTN_HOV  = "#388bfd"
BTN_PLAY = "#238636"
BTN_PAUS = "#9e6a03"
BTN_RSET = "#6e4091"
BTN_DIS  = "#1c2128"

C_J = ["#58a6ff", "#3fb950", "#f78166"]          # colores q1, q2, q3
JNAMES = ["q1", "q2", "q3"]

plt.rcParams.update({
    "figure.facecolor":  BG,
    "axes.facecolor":    PANEL,
    "axes.edgecolor":    BORDER,
    "axes.labelcolor":   TEXT,
    "axes.titlecolor":   ACCENT,
    "axes.grid":         True,
    "grid.color":        "#21262d",
    "grid.linewidth":    0.7,
    "xtick.color":       MUTED,
    "ytick.color":       MUTED,
    "text.color":        TEXT,
    "font.family":       "monospace",
    "font.size":         8,
})

# ═══════════════════════════════════════════════════════════════════════════════
#  PARÁMETROS DEL ROBOT
# ═══════════════════════════════════════════════════════════════════════════════
# Denavit-Hartenberg (idénticos a sim_tray.py)
_DH_A     = np.array([40.0,  180.0, 140.0])     # a1=40mm: offset horizontal del primer brazo desde el eje de la base
_DH_D     = np.array([0.0,     0.0,   0.0])     # mm
_DH_ALPHA = np.array([np.pi/2, 0.0,   0.0])     # rad

# Límites articulares (grados) — holgados para permitir q0/qf del sim original
Q_MIN = np.array([-180.0, -180.0, -180.0])
Q_MAX = np.array([ 270.0,  180.0,  180.0])

# Parámetros del firmware (brazo_rtos.ino / siservia.ino)
PPR_M12   = 6720.0        # pulsos por vuelta motores 1 y 2
PPR_M3    = 8640.0        # pulsos por vuelta motor 3
PPR       = np.array([PPR_M12, PPR_M12, PPR_M3])
DEADBAND  = 20            # pulsos — zona muerta del controlador P
PWM_MAX   = 180
PWM_MIN   = 60
PWM_RANGE_PULSES = 2000   # map(err, DEADBAND, 2000, PWM_MIN, PWM_MAX)

# Poses por defecto (mismas del sim_tray.py)
Q0_DEF = np.array([  0.0, 117.0, -118.0])
QF_DEF = np.array([245.0,  83.0,  -56.0])

# Discretización para la trayectoria cúbica
T_TOTAL_DEF = 5.0
DT          = 0.01


# ═══════════════════════════════════════════════════════════════════════════════
#  CINEMÁTICA
# ═══════════════════════════════════════════════════════════════════════════════
def dh_matrix(a, d, alpha, theta):
    ct, st = np.cos(theta), np.sin(theta)
    ca, sa = np.cos(alpha), np.sin(alpha)
    return np.array([
        [ct, -st*ca,  st*sa, a*ct],
        [st,  ct*ca, -ct*sa, a*st],
        [0.,     sa,     ca,    d],
        [0.,     0.,     0.,   1.],
    ])


def fk(q_deg):
    """Cinemática directa: devuelve lista de orígenes [O0, O1, O2, O3]."""
    q = np.deg2rad(q_deg)
    T = np.eye(4)
    origins = [T[:3, 3].copy()]
    for i in range(3):
        Ti = dh_matrix(_DH_A[i], _DH_D[i], _DH_ALPHA[i], q[i])
        T  = T @ Ti
        origins.append(T[:3, 3].copy())
    return np.array(origins)        # (4, 3)


def ee_pos(q_deg):
    return fk(q_deg)[-1]


# ═══════════════════════════════════════════════════════════════════════════════
#  CINEMÁTICA INVERSA (analítica)
#
#  Dado un punto objetivo (x, y, z) en el marco del mundo, devuelve los tres
#  ángulos articulares (q1, q2, q3) en grados. El robot es 3-DOF con:
#     q1: rotación de la base alrededor de Z₀ (vertical)
#     a₁: offset horizontal desde el eje de la base al eje del hombro
#     q2: hombro,  L₂ = a₂
#     q3: codo,    L₃ = a₃
#
#  Hay 2 soluciones geométricas (codo arriba / codo abajo). Se devuelve la
#  elegida por `elbow_up`. Si el punto está fuera del espacio de trabajo
#  (más lejos que L₂+L₃ o más cerca que |L₂−L₃|), devuelve None.
# ═══════════════════════════════════════════════════════════════════════════════
def ik(x, y, z, elbow_up=True):
    a1 = _DH_A[0]        # offset horizontal
    L2 = _DH_A[1]        # brazo
    L3 = _DH_A[2]        # antebrazo

    # q1: la base apunta hacia el objetivo en el plano X-Y
    q1 = np.arctan2(y, x)

    # En el plano vertical del brazo (tras rotar por q1):
    #   r = radio horizontal desde el eje del hombro
    #   s = altura (z)
    r_total = np.hypot(x, y)
    r = r_total - a1
    s = z

    # Verificar alcance
    L = np.hypot(r, s)
    if L > (L2 + L3) + 1e-9 or L < abs(L2 - L3) - 1e-9:
        return None      # fuera del espacio de trabajo

    # Ley de cosenos: ángulo del codo
    D = (r*r + s*s - L2*L2 - L3*L3) / (2.0 * L2 * L3)
    D = np.clip(D, -1.0, 1.0)
    sign = 1.0 if elbow_up else -1.0
    q3 = sign * np.arctan2(np.sqrt(1.0 - D*D), D)

    # Ángulo del hombro
    q2 = np.arctan2(s, r) - np.arctan2(L3*np.sin(q3), L2 + L3*np.cos(q3))

    return np.rad2deg(np.array([q1, q2, q3]))


def workspace_bounds():
    """Radios mínimo y máximo del espacio de trabajo, y altura máxima."""
    a1, L2, L3 = _DH_A
    r_max = a1 + (L2 + L3)
    r_min = max(0.0, a1 - (L2 + L3))     # si a1 < L2+L3, el robot puede llegar a 0
    # Altura (en el plano del brazo): el alcance vertical desde el hombro es L2+L3
    z_max =  (L2 + L3)
    z_min = -(L2 + L3)
    return r_min, r_max, z_min, z_max


# ═══════════════════════════════════════════════════════════════════════════════
#  PERFIL QUÍNTICO  (polinomio de grado 5 — "perfil de velocidad cúbico")
#
#  Condiciones de frontera:
#    q(0)   = q0        q(tf)   = qf
#    qd(0)  = 0         qd(tf)  = 0
#    qdd(0) = 0         qdd(tf) = 0
#
#  Resultado:
#    q(t)   = polinomio grado 5  (rampa suavísima en S)
#    qd(t)  = polinomio grado 4  (pico simétrico, perfil tipo campana)
#    qdd(t) = polinomio grado 3  (CÚBICA en el tiempo  ← de aquí el nombre)
#    qddd(t)= parabólico         (jerk finito, suave)
#
#  Coeficientes (con D = qf - q0):
#    a0 = q0,  a1 = a2 = 0
#    a3 =  10·D/tf³
#    a4 = -15·D/tf⁴
#    a5 =   6·D/tf⁵
# ═══════════════════════════════════════════════════════════════════════════════
def perfil_quintico(q0, qf, t, tf):
    n = len(t)
    q, qd, qdd = np.zeros((3, n)), np.zeros((3, n)), np.zeros((3, n))
    for j in range(3):
        D = qf[j] - q0[j]
        a3 =  10.0 * D / tf**3
        a4 = -15.0 * D / tf**4
        a5 =   6.0 * D / tf**5
        q[j]   = q0[j] + a3*t**3 +   a4*t**4 +   a5*t**5
        qd[j]  =        3*a3*t**2 + 4*a4*t**3 + 5*a5*t**4
        qdd[j] =        6*a3*t   + 12*a4*t**2 + 20*a5*t**3
    return q, qd, qdd


# ═══════════════════════════════════════════════════════════════════════════════
#  SIMULACIÓN DEL LAZO DE CONTROL DEL FIRMWARE
# ═══════════════════════════════════════════════════════════════════════════════
def sim_firmware_loop(q_start_deg, q_ref_deg, dt=0.02, t_max=6.0,
                      k_planta=0.6):
    """
    Replica el lazo del .ino (controlMotor / tareaMotor):
        error_pulsos = posRef - pos
        si |error| <= DEADBAND  -> motor para
        sino  PWM = map(|error|, DEADBAND, 2000, PWM_MIN, PWM_MAX)  (saturado)
        sentido = sign(error)

    La planta se modela como integrador de primer orden:
        v_pulsos = k_planta * PWM * sign(error)     [pulsos/ciclo]
        pos(k+1) = pos(k) + v_pulsos * dt_ratio

    Retorna arreglos de tiempo, posiciones (deg), errores (deg) y PWM firmados.
    El parámetro k_planta ajusta qué tan "rápido" responde el motor simulado.
    """
    n = int(t_max / dt) + 1
    t = np.arange(n) * dt

    # A pulsos
    pos_ref_p = (q_ref_deg   / 360.0) * PPR
    pos_p     = (q_start_deg / 360.0) * PPR.copy()

    pos_hist   = np.zeros((3, n))
    pwm_hist   = np.zeros((3, n))
    err_hist   = np.zeros((3, n))   # en pulsos (para graficar se convierte a deg)

    for k in range(n):
        for j in range(3):
            error = pos_ref_p[j] - pos_p[j]
            abserr = abs(error)
            if abserr <= DEADBAND:
                pwm = 0
            else:
                # map(abserr, DEADBAND, 2000, PWM_MIN, PWM_MAX)
                x = (abserr - DEADBAND) / (PWM_RANGE_PULSES - DEADBAND)
                pwm = PWM_MIN + x * (PWM_MAX - PWM_MIN)
                pwm = max(PWM_MIN, min(PWM_MAX, pwm))

            signo = 1.0 if error > 0 else (-1.0 if error < 0 else 0.0)

            # Planta simplificada
            v_pulsos_por_s = k_planta * pwm * signo   # pulsos/s
            pos_p[j] += v_pulsos_por_s * dt

            pos_hist[j, k] = pos_p[j]
            pwm_hist[j, k] = pwm * signo
            err_hist[j, k] = error

    # Convertir a grados
    pos_deg_hist = pos_hist / PPR[:, None] * 360.0
    err_deg_hist = err_hist / PPR[:, None] * 360.0
    return t, pos_deg_hist, pwm_hist, err_deg_hist


# ═══════════════════════════════════════════════════════════════════════════════
#  WIDGETS AUXILIARES
# ═══════════════════════════════════════════════════════════════════════════════
def make_labeled_entry(parent, label, default, width=7):
    frm = tk.Frame(parent, bg=PANEL)
    tk.Label(frm, text=label, bg=PANEL, fg=MUTED,
             font=("Courier New", 9)).pack(side="left", padx=(0, 4))
    var = tk.StringVar(value=str(default))
    e = tk.Entry(frm, textvariable=var, width=width,
                 bg="#0a0e14", fg=ACCENT, insertbackground=ACCENT,
                 relief="flat", font=("Courier New", 10),
                 highlightthickness=1, highlightbackground=BORDER,
                 highlightcolor=BTN_HOV)
    e.pack(side="left")
    return frm, var


# ═══════════════════════════════════════════════════════════════════════════════
#  APLICACIÓN PRINCIPAL
# ═══════════════════════════════════════════════════════════════════════════════
class BrazoApp(tk.Tk):
    def __init__(self):
        super().__init__()
        self.title("Brazo Robótico 3-DOF — Simulador Integrado")
        self.configure(bg=BG)
        try:
            self.state("zoomed")
        except tk.TclError:
            self.geometry("1400x850")
        self.protocol("WM_DELETE_WINDOW", self._on_close)

        self._tab = 0
        self._job = None

        # Estado articular actual (se usa en la pestaña 3D y como q_inicio en trayectoria)
        self._q_current = Q0_DEF.copy()

        self._build_header()
        self._build_tabs()
        self._build_statusbar()
        self._build_figures()

        self._switch_tab(0)

    # ──────────────────────────────────────────────────────────
    def _build_header(self):
        hdr = tk.Frame(self, bg=BG, pady=6)
        hdr.pack(fill="x", side="top")
        tk.Label(hdr, text="BRAZO ROBOTICO 3-DOF  —  SIMULADOR INTEGRADO",
                 bg=BG, fg=ACCENT, font=("Courier New", 13, "bold")).pack()
        tk.Label(hdr,
                 text="DH: a=[40, 180, 140] mm  d=[0, 0, 0] mm  alpha=[90,0,0] deg   |   "
                      "PPR: M1/M2=6720  M3=8640   |   PWM 60-180  deadband=20",
                 bg=BG, fg=MUTED, font=("Courier New", 8)).pack()
        tk.Frame(self, bg=BORDER, height=1).pack(fill="x", side="top")

    def _build_tabs(self):
        bar = tk.Frame(self, bg=PANEL, pady=4)
        bar.pack(fill="x", side="top")
        self._tab_btns = []
        labels = ["  1. Vista 3D  ", "  2. Motores + PID  ", "  3. Trayectoria quintica (vel cubica)  "]
        for i, lbl in enumerate(labels):
            b = tk.Button(bar, text=lbl,
                          bg=BTN_HOV if i == 0 else BTN_BG,
                          fg=ACCENT if i == 0 else TEXT,
                          relief="flat", bd=0,
                          font=("Courier New", 10, "bold"),
                          cursor="hand2", padx=14, pady=7,
                          command=lambda i=i: self._switch_tab(i))
            b.pack(side="left", padx=4)
            self._tab_btns.append(b)
        tk.Frame(self, bg=BORDER, height=1).pack(fill="x", side="top")

    def _build_statusbar(self):
        tk.Frame(self, bg=BORDER, height=1).pack(fill="x", side="bottom")
        sb = tk.Frame(self, bg="#0a0e14", pady=3)
        sb.pack(fill="x", side="bottom")
        self._lbl_status = tk.Label(
            sb, text="Listo.", bg="#0a0e14", fg=MUTED,
            font=("Courier New", 8), anchor="w")
        self._lbl_status.pack(side="left", padx=10)

    # ──────────────────────────────────────────────────────────
    #  FIGURAS
    # ──────────────────────────────────────────────────────────
    def _build_figures(self):
        self._main = tk.Frame(self, bg=BG)
        self._main.pack(fill="both", expand=True, side="top")

        # ---- Frames por pestaña ------------------------------------------------
        self._frame_3d   = tk.Frame(self._main, bg=BG)
        self._frame_pid  = tk.Frame(self._main, bg=BG)
        self._frame_traj = tk.Frame(self._main, bg=BG)

        self._build_tab_3d(self._frame_3d)
        self._build_tab_pid(self._frame_pid)
        self._build_tab_traj(self._frame_traj)

    def _switch_tab(self, idx):
        # Parar cualquier animación pendiente de otras pestañas
        if self._job is not None:
            self.after_cancel(self._job)
            self._job = None

        for i, b in enumerate(self._tab_btns):
            if i == idx:
                b.config(bg=BTN_HOV, fg=ACCENT)
            else:
                b.config(bg=BTN_BG, fg=TEXT)

        for f in (self._frame_3d, self._frame_pid, self._frame_traj):
            f.pack_forget()
        target = [self._frame_3d, self._frame_pid, self._frame_traj][idx]
        target.pack(fill="both", expand=True)
        self._tab = idx

    # ═══════════════════════════════════════════════════════════════════════════
    #  PESTAÑA 1 — VISTA 3D
    # ═══════════════════════════════════════════════════════════════════════════
    def _build_tab_3d(self, parent):
        # Panel de controles (sliders)
        ctl = tk.Frame(parent, bg=PANEL, pady=10)
        ctl.pack(fill="x", side="bottom")

        tk.Label(ctl, text="Angulos articulares (deg)",
                 bg=PANEL, fg=ACCENT,
                 font=("Courier New", 10, "bold")).pack(side="left", padx=(14, 20))

        self._sliders_3d = []
        self._lbl_slider = []
        for j in range(3):
            col = tk.Frame(ctl, bg=PANEL)
            col.pack(side="left", padx=10)
            tk.Label(col, text=JNAMES[j], bg=PANEL,
                     fg=C_J[j], font=("Courier New", 10, "bold")).pack()
            var = tk.DoubleVar(value=self._q_current[j])
            s = tk.Scale(col, from_=Q_MIN[j], to=Q_MAX[j],
                         resolution=1.0, orient="horizontal",
                         length=220, bg=PANEL, fg=TEXT,
                         troughcolor=BTN_BG, highlightthickness=0,
                         font=("Courier New", 8),
                         variable=var,
                         command=lambda _v, j=j: self._on_slider_3d(j))
            s.pack()
            self._sliders_3d.append(var)

        # Botón reset
        tk.Frame(ctl, bg=BORDER, width=2, height=40).pack(side="left", padx=14)
        tk.Button(ctl, text="  Pose inicial  ",
                  bg=BTN_RSET, fg=ACCENT,
                  relief="flat", bd=0,
                  font=("Courier New", 10, "bold"), cursor="hand2",
                  padx=14, pady=6,
                  command=self._reset_pose_3d).pack(side="left", padx=6)

        tk.Button(ctl, text="  Cero (q=0)  ",
                  bg=BTN_BG, fg=TEXT,
                  relief="flat", bd=0,
                  font=("Courier New", 10, "bold"), cursor="hand2",
                  padx=14, pady=6,
                  command=self._zero_pose_3d).pack(side="left", padx=6)

        # Info efector final
        self._lbl_ee = tk.Label(ctl, text="", bg=PANEL, fg=ACCENT,
                                font=("Courier New", 10, "bold"))
        self._lbl_ee.pack(side="left", padx=20)

        # Figura 3D
        self._fig3d = plt.Figure(figsize=(12, 7), facecolor=BG)
        self._ax3d  = self._fig3d.add_subplot(111, projection="3d")
        self._fig3d.subplots_adjust(left=0.02, right=0.98, top=0.96, bottom=0.04)

        self._canvas3d = FigureCanvasTkAgg(self._fig3d, master=parent)
        self._canvas3d.get_tk_widget().pack(fill="both", expand=True, side="top")

        self._draw_3d(self._q_current)

    def _on_slider_3d(self, j):
        self._q_current[j] = self._sliders_3d[j].get()
        self._draw_3d(self._q_current)

    def _reset_pose_3d(self):
        self._q_current = Q0_DEF.copy()
        for j in range(3):
            self._sliders_3d[j].set(self._q_current[j])
        self._draw_3d(self._q_current)

    def _zero_pose_3d(self):
        self._q_current = np.zeros(3)
        for j in range(3):
            self._sliders_3d[j].set(0.0)
        self._draw_3d(self._q_current)

    def _draw_3d(self, q_deg):
        ax = self._ax3d
        ax.clear()
        ax.set_facecolor("#0a0f16")

        origins = fk(q_deg)                  # (4,3)
        xs, ys, zs = origins[:, 0], origins[:, 1], origins[:, 2]

        # Suelo (malla tenue)
        R = 350
        ax.plot([-R, R], [0, 0], [0, 0], color="#30363d", lw=0.6)
        ax.plot([0, 0], [-R, R], [0, 0], color="#30363d", lw=0.6)

        # Eslabones
        link_colors = ["#8b949e", "#58a6ff", "#3fb950", "#f78166"]
        ax.plot(xs, ys, zs, color="#8b949e", lw=1.0, alpha=0.4)     # traza guía
        for i in range(3):
            ax.plot([xs[i], xs[i+1]], [ys[i], ys[i+1]], [zs[i], zs[i+1]],
                    color=C_J[i], lw=5, solid_capstyle="round")

        # Articulaciones
        ax.scatter(xs[:-1], ys[:-1], zs[:-1], color=ACCENT,
                   s=70, edgecolors="#000", linewidth=1, zorder=5)
        # Efector final
        ax.scatter([xs[-1]], [ys[-1]], [zs[-1]], color="#f78166",
                   s=140, marker="*", edgecolors="#000", linewidth=1, zorder=6)

        # Base
        theta = np.linspace(0, 2*np.pi, 40)
        ax.plot(40*np.cos(theta), 40*np.sin(theta), np.zeros_like(theta),
                color=MUTED, lw=1.2)

        # Ejes del mundo (pequeños, en origen)
        L = 60
        ax.plot([0, L], [0, 0], [0, 0], color="#f85149", lw=1.2)
        ax.plot([0, 0], [0, L], [0, 0], color="#3fb950", lw=1.2)
        ax.plot([0, 0], [0, 0], [0, L], color="#58a6ff", lw=1.2)

        ax.set_xlim(-R, R); ax.set_ylim(-R, R); ax.set_zlim(-R, R)
        ax.set_xlabel("X (mm)", fontsize=8)
        ax.set_ylabel("Y (mm)", fontsize=8)
        ax.set_zlabel("Z (mm)", fontsize=8)
        ax.set_title(f"Pose actual: q1={q_deg[0]:+.1f}°  "
                     f"q2={q_deg[1]:+.1f}°  q3={q_deg[2]:+.1f}°",
                     fontsize=9, color=ACCENT, pad=8)
        ax.tick_params(labelsize=7)
        # Fondo del panel 3D
        ax.xaxis.pane.set_facecolor("#0a0f16")
        ax.yaxis.pane.set_facecolor("#0a0f16")
        ax.zaxis.pane.set_facecolor("#0a0f16")
        ax.xaxis.pane.set_edgecolor(BORDER)
        ax.yaxis.pane.set_edgecolor(BORDER)
        ax.zaxis.pane.set_edgecolor(BORDER)

        ee = origins[-1]
        self._lbl_ee.config(
            text=f"Efector final: ({ee[0]:+7.1f}, {ee[1]:+7.1f}, {ee[2]:+7.1f}) mm")
        self._canvas3d.draw_idle()

    # ═══════════════════════════════════════════════════════════════════════════
    #  PESTAÑA 2 — MOTORES + PID (simulación del lazo del firmware)
    # ═══════════════════════════════════════════════════════════════════════════
    def _build_tab_pid(self, parent):
        # Panel superior de parámetros
        ctl = tk.Frame(parent, bg=PANEL, pady=9)
        ctl.pack(fill="x", side="bottom")

        tk.Label(ctl, text="Posicion inicial (deg):",
                 bg=PANEL, fg=MUTED,
                 font=("Courier New", 9)).pack(side="left", padx=(14, 6))
        self._pid_q0 = []
        for j in range(3):
            frm, var = make_labeled_entry(ctl, JNAMES[j], Q0_DEF[j])
            frm.pack(side="left", padx=4); self._pid_q0.append(var)

        tk.Frame(ctl, bg=BORDER, width=2, height=30).pack(side="left", padx=10)

        tk.Label(ctl, text="Referencia (deg):",
                 bg=PANEL, fg=MUTED,
                 font=("Courier New", 9)).pack(side="left", padx=(6, 6))
        self._pid_qf = []
        for j in range(3):
            frm, var = make_labeled_entry(ctl, JNAMES[j], QF_DEF[j])
            frm.pack(side="left", padx=4); self._pid_qf.append(var)
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

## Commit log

2026-03-17 Actualizacion archivos
    [Arm1.STL, Arm2.STL, BaseR.STL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]
2026-03-18 Actas de trabajo del proyecto
2026-03-25 Diseño PCB para mayor orden de conexiones
    [roboTin-B_Cu.gbr, roboTin-B_Mask.gbr, roboTin-Edge_Cuts.gbr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]
2026-04-21 some more hardware
    [GearedArm1v2.STL, GearedArm1v2_alt.STL, Gripped.stl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]
2026-05-26 A lil bit of everything ;p
    [A1.STL, A2.STL, B1.STL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]
2026-05-26 some more 📦
2026-05-26 assembly pics
2026-05-26 assembly picture update
